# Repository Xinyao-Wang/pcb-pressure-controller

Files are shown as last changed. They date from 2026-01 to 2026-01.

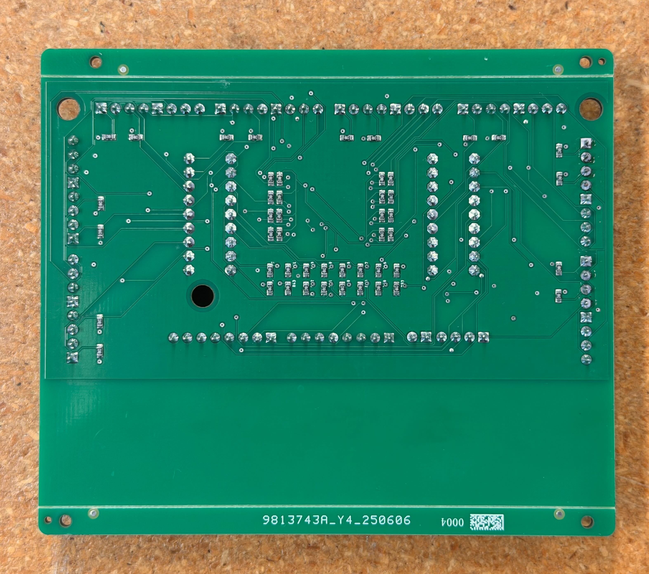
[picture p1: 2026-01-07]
pcb_bottom.jpg

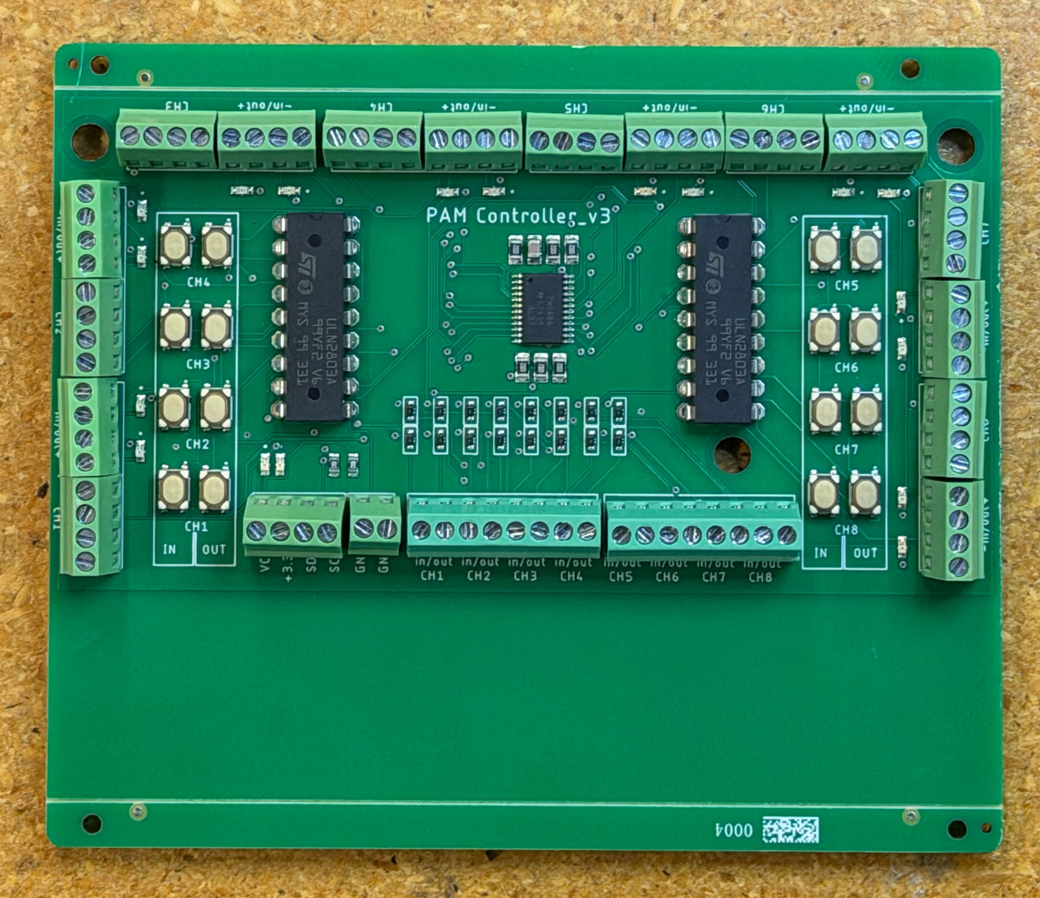
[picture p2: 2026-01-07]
pcb_top.jpg

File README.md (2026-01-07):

# PCB Pressure Controller

This repository contains the PCB design for a pressure control system used to drive and measure pneumatic artificial muscles (PAMs). The board interfaces with multiple pressure sensors and solenoid valves and was validated in hardware experiments.

## System Overview

The PCB performs two main functions:

1. **Pressure sensing** for multiple PAMs using digital pressure sensors over I2C.
2. **Valve actuation** using solenoid valves driven through transistor arrays.

The system was designed to work with a BeagleBone Black as the host controller.

## Pressure Sensing (I2C)

- **Sensor:** Honeywell 150PG2A3  
  - Range: 0–150 psi  
  - Interface: I2C (address 0x28)
- **Challenge:** All sensors share the same fixed I2C address.
- **Solution:** TCA9548A I2C multiplexer
  - Supports up to 8 channels
  - Configured at address `0x70`
  - Allows multiple identical sensors on a single I2C bus

**Electrical details:**
- I2C pull-up resistors: 1.8 kΩ on the main bus
- Sensor-side pull-ups: 1 kΩ
- Multiplexer connected directly to the BeagleBone Black I2C interface

## Valve Control

- **Actuators:** 5 V solenoid valves
- **Driver:** ULN2803A Darlington transistor array
  - Used to sink valve current beyond GPIO capability
  - Protects the controller from inductive loads

### Manual Control and Indicators
- Push-button switches for manual valve actuation
- Per-valve LED indicators showing activation state
- Additional LEDs indicating:
  - Valve power (VCC)
  - Transistor supply power

The valve drive stage is adaptable to valves with different voltage requirements by modifying the supply rail.

## Power

- Valve and transistor power supplied at 5 V
- 5 V rail provided by the BeagleBone Black in the current setup
- Power indicators included for debugging and bring-up

## Repository Contents

- schematic.pdf — Full schematic
- layout.pdf — PCB layout
- pcb_top.jpg — Assembled board (top)
- pcb_bottom.jpg — Assembled board (bottom)
- eagle/ — EAGLE schematic and board files
- CAMOutputs/ — Gerbers
- BOM.csv — Bill of materials

## Design Ownership

I designed the schematic, PCB layout, pressure sensing architecture, and valve driver circuitry, and validated the board in experimental PAM control setups.

## Notes

This PCB was designed for experimental reliability, with clear separation between sensing, actuation, and power domains, and with features added to simplify bring-up and debugging.

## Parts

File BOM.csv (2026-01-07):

Qty | Designator | Footprint | Comment | LCSC part # | Device | Description
1 | J2 | MOLEX-1X2 | Should be a screw terminal 1x2 |  | CONN_02POLAR | Multi connection point. Often used as Generic Header-pin footprint for 0.1 inch spaced/style header connections
17 | J1, J4, J5, J6, J7, J8, J9, J10, J11, J12, J14, J15, J16, J17, J18, J19, J20 | MOLEX-1X4 | Should be screw terminals 1x4 |  | CONN_04POLAR | Multi connection point. Often used as Generic Header-pin footprint for 0.1 inch spaced/style header connections
16 | D19, D20, D21, D22, D23, D24, D25, D26, D27, D28, D29, D30, D31, D32, D33, D34 | SOD-523 | diode | C3040060 | DIODESOD-523 | Diode
1 | U1 | TSSOP24 | TCA9548APWR | C130026 | TCA9548A | TCA9548A I2C Multiplexer
5 | R53, R54, R55, R56, R57, R58 | 0805-NO | 10K | C17414 | RESISTOR0805_NOOUTLINE | Resistors
1 | C1 | 0805-NO | 10uF | C1713 | CAP_CERAMIC0805-NOOUTLINE | Ceramic Capacitors
50 | R3, R4, R5, R6, R7, R8, R9, R10, R11, R12, R13, R14, R15, R16, R17, R18, R19, R20, R21, R22, R23, R24, R25, R26, R27, R28, R29, R30, R31, R32, R33, R34, R35, R36, R37, R38, R39, R40, R41, R42, R43, R44, R45, R46, R47, R48, R49, R50, R51, R52 | RESC1607X60N | 1K | C22548 | RC0603FR-071KL
2 | J3, J13 | TE_282834-8 | Should be screw terminals 1x8 |  | 282834-8
18 | D1, D2, D3, D4, D5, D6, D7, D8, D9, D10, D11, D12, D13, D14, D15, D16, D17, D18 | LEDC1608X35N | LTST-C190KGKT | C125094 | LTST-C190KGKT
16 | S1, S2, S3, S4, S5, S6, S7, S8, S9, S10, S11, S12, S13, S14, S15, S16 | SW_SKRPACE010 | SKRPACE010 | C139797 | SKRPACE010
2 | IC1, IC2 | ULN2803A |  | C73936 | ULN2803A | Eight paths DIP-18 Darlington Transistor Arrays ROHS

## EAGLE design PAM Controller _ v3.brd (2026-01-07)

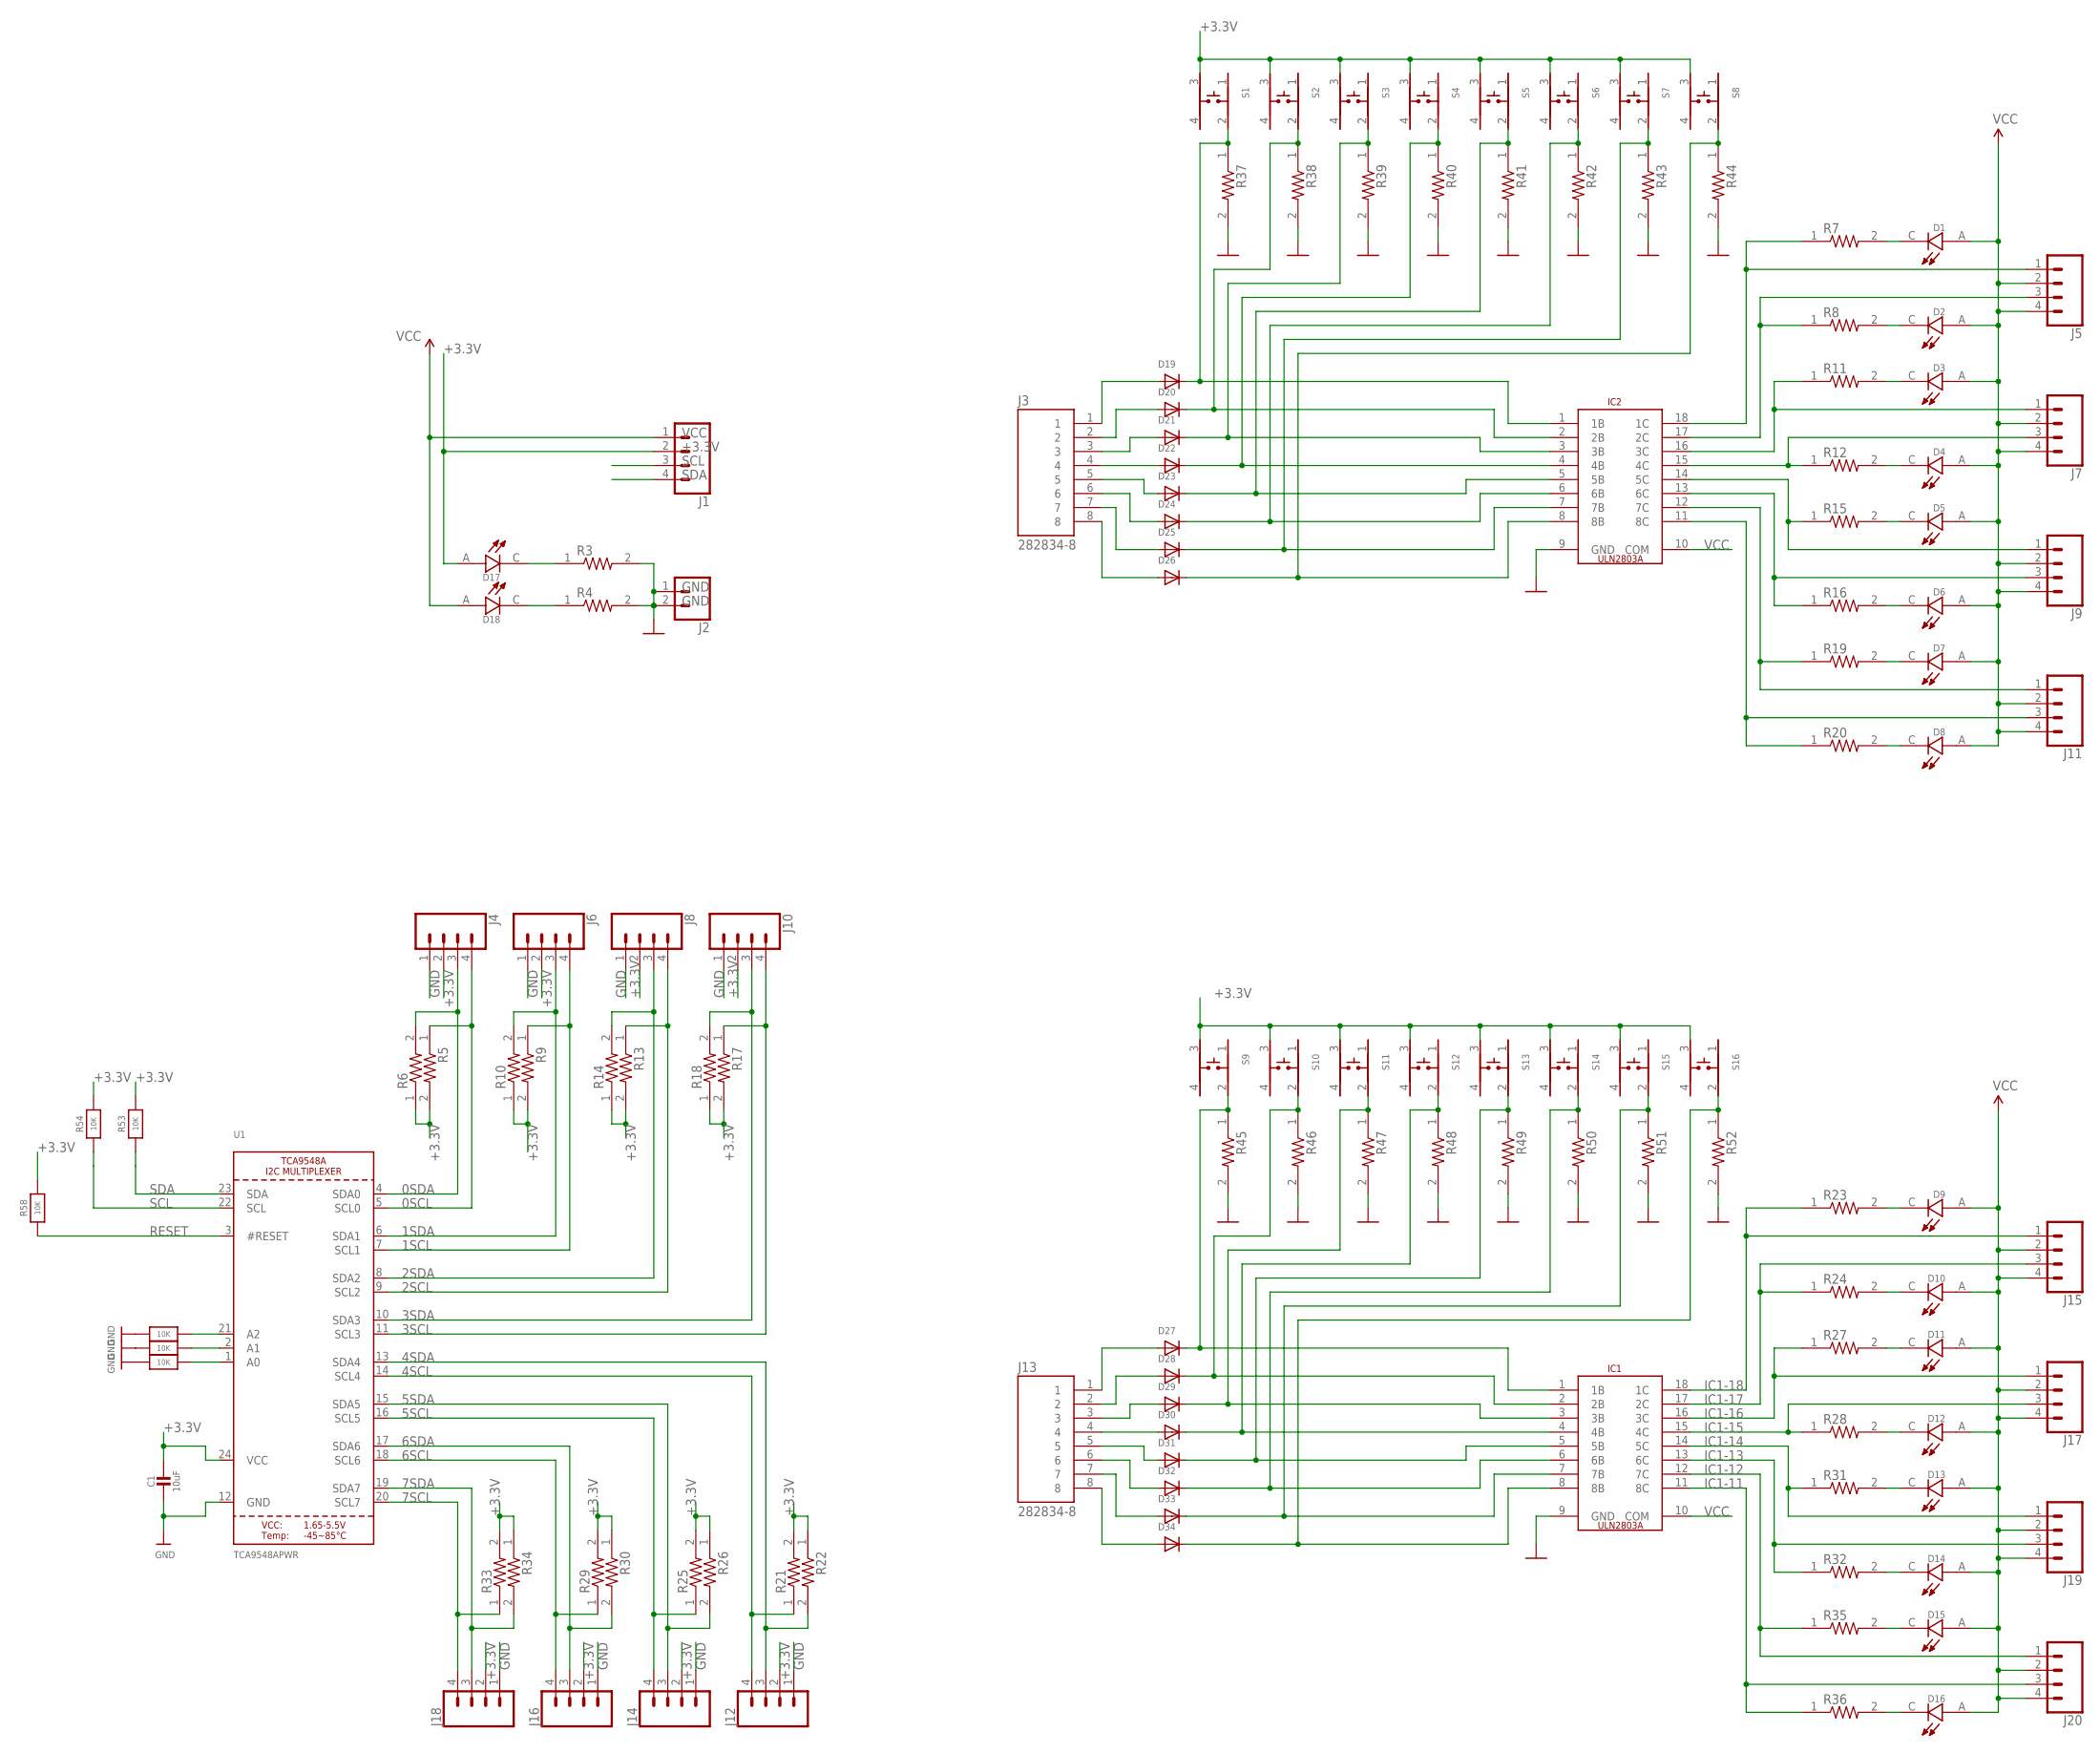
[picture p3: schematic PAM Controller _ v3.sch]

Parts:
C1: 10uF; 0805-NO
D1, D2, D3, D4, D5, D6, D7, D8, D9, D10, D11, D12, D13, D14, D15, D16, D17, D18: LTST-C190KGKT; LEDC1608X35N
D19, D20, D21, D22, D23, D24, D25, D26, D27, D28, D29, D30, D31, D32, D33, D34: DIODESOD-523; SOD-523
IC1, IC2: ULN2803A
J1, J4, J5, J6, J7, J8, J9, J10, J11, J12, J14, J15, J16, J17, J18, J19, J20: CONN_04POLAR; MOLEX-1X4
J2: CONN_02POLAR; MOLEX-1X2
J3, J13: 282834-8; TE_282834-8
R3, R4, R5, R6, R7, R8, R9, R10, R11, R12, R13, R14, R15, R16, R17, R18, R19, R20, R21, R22, R23, R24, R25, R26, R27, R28, R29, R30, R31, R32, R33, R34, R35, R36, R37, R38, R39, R40, R41, R42, R43, R44, R45, R46, R47, R48, R49, R50, R51, R52: 1K; RESC1607X60N
R53, R54, R55, R56, R57, R58: 10K; 0805-NO
S1, S2, S3, S4, S5, S6, S7, S8, S9, S10, S11, S12, S13, S14, S15, S16: SKRPACE010; SW_SKRPACE010
U1: TCA9548APWR; TSSOP24

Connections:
0SCL: J4.4, R5.1, U1.5 (SCL0)
0SDA: J4.3, R6.2, U1.4 (SDA0)
1SCL: J6.4, R9.1, U1.7 (SCL1)
1SDA: J6.3, R10.2, U1.6 (SDA1)
2SCL: J8.4, R13.1, U1.9 (SCL2)
2SDA: J8.3, R14.2, U1.8 (SDA2)
3SCL: J10.4, R17.1, U1.11 (SCL3)
3SDA: J10.3, R18.2, U1.10 (SDA3)
4SCL: J12.4, R21.1, U1.14 (SCL4)
4SDA: J12.3, R22.2, U1.13 (SDA4)
5SCL: J14.4, R25.1, U1.16 (SCL5)
5SDA: J14.3, R26.2, U1.15 (SDA5)
6SCL: J16.4, R29.1, U1.18 (SCL6)
6SDA: J16.3, R30.2, U1.17 (SDA6)
7SCL: J18.4, R33.1, U1.20 (SCL7)
7SDA: J18.3, R34.2, U1.19 (SDA7)
+3.3V: C1.1, D17.A, J1.2, J4.2, J6.2, J8.2, J10.2, J12.2, J14.2, J16.2, J18.2, R5.2, R6.1, R9.2, R10.1, R13.2, R14.1, R17.2, R18.1, R21.2, R22.1, R25.2, R26.1, R29.2, R30.1, R33.2, R34.1, R53.2, R54.2, R58.2, S1.3, S2.3, S3.3, S4.3, S5.3, S6.3, S7.3, S8.3, S9.3, S10.3, S11.3, S12.3, S13.3, S14.3, S15.3, S16.3, U1.24 (VCC)
GND: C1.2, IC1.9 (GND), IC2.9 (GND), J2.1, J2.2, J4.1, J6.1, J8.1, J10.1, J12.1, J14.1, J16.1, J18.1, R3.2, R4.2, R37.2, R38.2, R39.2, R40.2, R41.2, R42.2, R43.2, R44.2, R45.2, R46.2, R47.2, R48.2, R49.2, R50.2, R51.2, R52.2, R55.2, R56.2, R57.2, U1.12 (GND)
IC1-11: IC1.11 (8C), J20.3, R36.1
IC1-12: IC1.12 (7C), J20.1, R35.1
IC1-13: IC1.13 (6C), J19.3, R32.1
IC1-14: IC1.14 (5C), J19.1, R31.1
IC1-15: IC1.15 (4C), J17.3, R28.1
IC1-16: IC1.16 (3C), J17.1, R27.1
IC1-17: IC1.17 (2C), J15.3, R24.1
IC1-18: IC1.18 (1C), J15.1, R23.1
IC2-11: IC2.11 (8C), J11.3, R20.1
IC2-12: IC2.12 (7C), J11.1, R19.1
IC2-13: IC2.13 (6C), J9.3, R16.1
IC2-14: IC2.14 (5C), J9.1, R15.1
IC2-15: IC2.15 (4C), J7.3, R12.1
IC2-16: IC2.16 (3C), J7.1, R11.1
IC2-17: IC2.17 (2C), J5.3, R8.1
IC2-18: IC2.18 (1C), J5.1, R7.1
unnamed: D19.K (C), IC2.1 (1B), R37.1, S1.2
unnamed: D19.A, J3.1
unnamed: D20.A, J3.2
unnamed: D21.A, J3.3
unnamed: D22.A, J3.4
unnamed: D23.A, J3.5
unnamed: D24.A, J3.6
unnamed: D25.A, J3.7
unnamed: D27.A, J13.1
unnamed: D27.K (C), IC1.1 (1B), R45.1, S9.2
unnamed: R56.1, U1.2 (A1)
unnamed: R57.1, U1.1 (A0)
unnamed: D28.K (C), IC1.2 (2B), R46.1, S10.2
unnamed: R55.1, U1.21 (A2)
unnamed: D30.A, J13.4
unnamed: D28.A, J13.2
unnamed: D29.A, J13.3
unnamed: D34.A, J13.8
unnamed: D33.A, J13.7
unnamed: D14.C, R32.2
unnamed: D15.C, R35.2
unnamed: D26.A, J3.8
unnamed: D32.A, J13.6
unnamed: D20.K (C), IC2.2 (2B), R38.1, S2.2
unnamed: D21.K (C), IC2.3 (3B), R39.1, S3.2
unnamed: D22.K (C), IC2.4 (4B), R40.1, S4.2
unnamed: D23.K (C), IC2.5 (5B), R41.1, S5.2
unnamed: D24.K (C), IC2.6 (6B), R42.1, S6.2
unnamed: D25.K (C), IC2.7 (7B), R43.1, S7.2
unnamed: D26.K (C), IC2.8 (8B), R44.1, S8.2
unnamed: D29.K (C), IC1.3 (3B), R47.1, S11.2
unnamed: D31.A, J13.5
unnamed: D30.K (C), IC1.4 (4B), R48.1, S12.2
unnamed: D31.K (C), IC1.5 (5B), R49.1, S13.2
unnamed: D32.K (C), IC1.6 (6B), R50.1, S14.2
unnamed: D33.K (C), IC1.7 (7B), R51.1, S15.2
unnamed: D34.K (C), IC1.8 (8B), R52.1, S16.2
unnamed: D16.C, R36.2
unnamed: D12.C, R28.2
unnamed: D13.C, R31.2
unnamed: D11.C, R27.2
unnamed: D10.C, R24.2
unnamed: D9.C, R23.2
unnamed: D8.C, R20.2
unnamed: D7.C, R19.2
unnamed: D6.C, R16.2
unnamed: D1.C, R7.2
unnamed: D17.C, R3.1
unnamed: D18.C, R4.1
unnamed: D5.C, R15.2
unnamed: D4.C, R12.2
unnamed: D3.C, R11.2
unnamed: D2.C, R8.2
RESET: R58.1, U1.3 (#RESET)
SCL: J1.4, R54.1, U1.22 (SCL)
SDA: J1.3, R53.1, U1.23 (SDA)
VCC: D1.A, D2.A, D3.A, D4.A, D5.A, D6.A, D7.A, D8.A, D9.A, D10.A, D11.A, D12.A, D13.A, D14.A, D15.A, D16.A, D18.A, IC1.10 (COM), IC2.10 (COM), J1.1, J5.2, J5.4, J7.2, J7.4, J9.2, J9.4, J11.2, J11.4, J15.2, J15.4, J17.2, J17.4, J19.2, J19.4, J20.2, J20.4

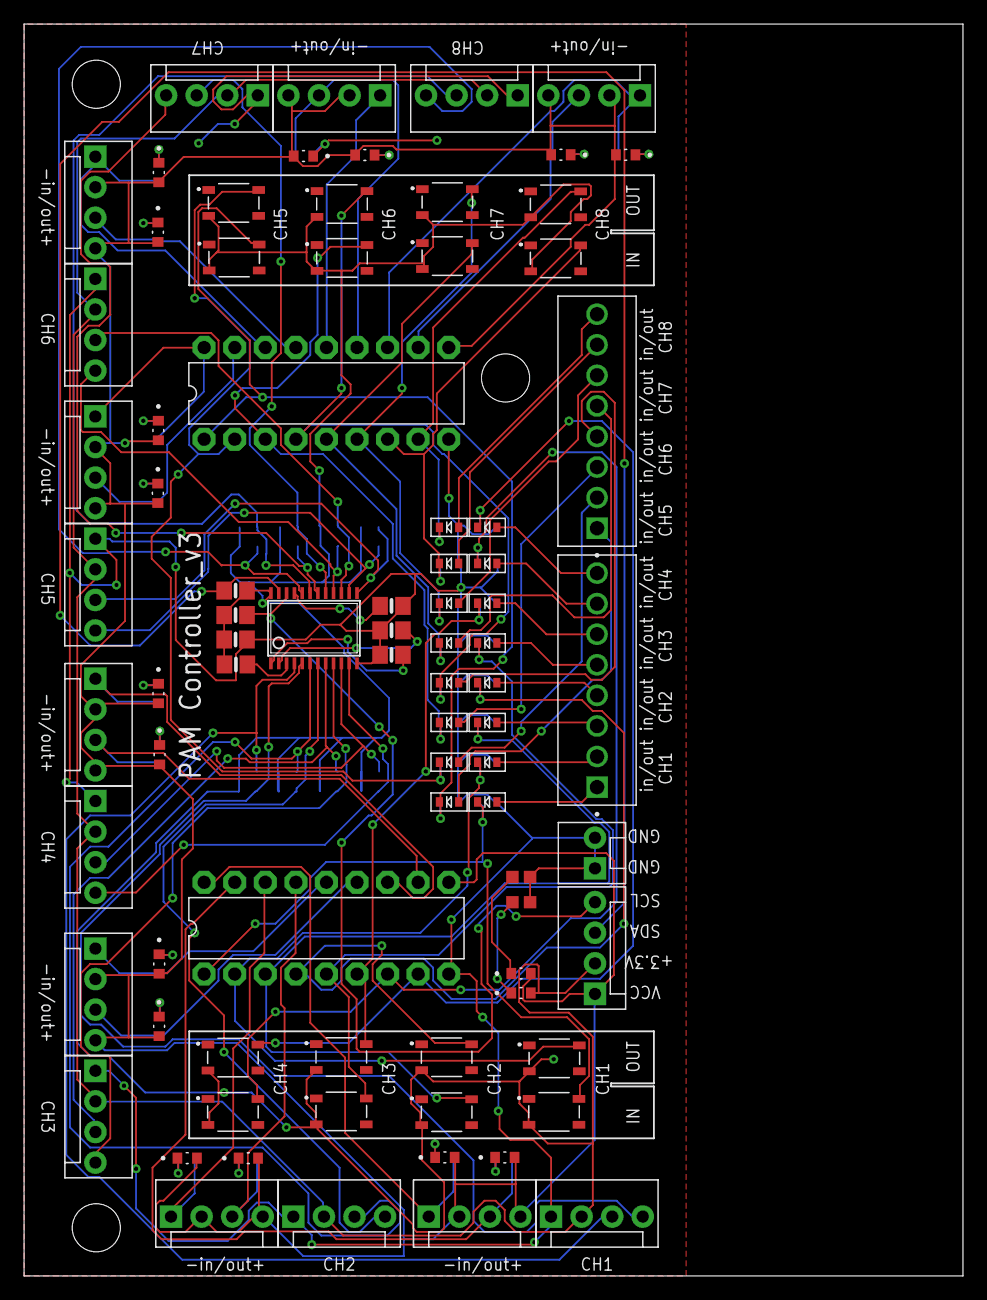
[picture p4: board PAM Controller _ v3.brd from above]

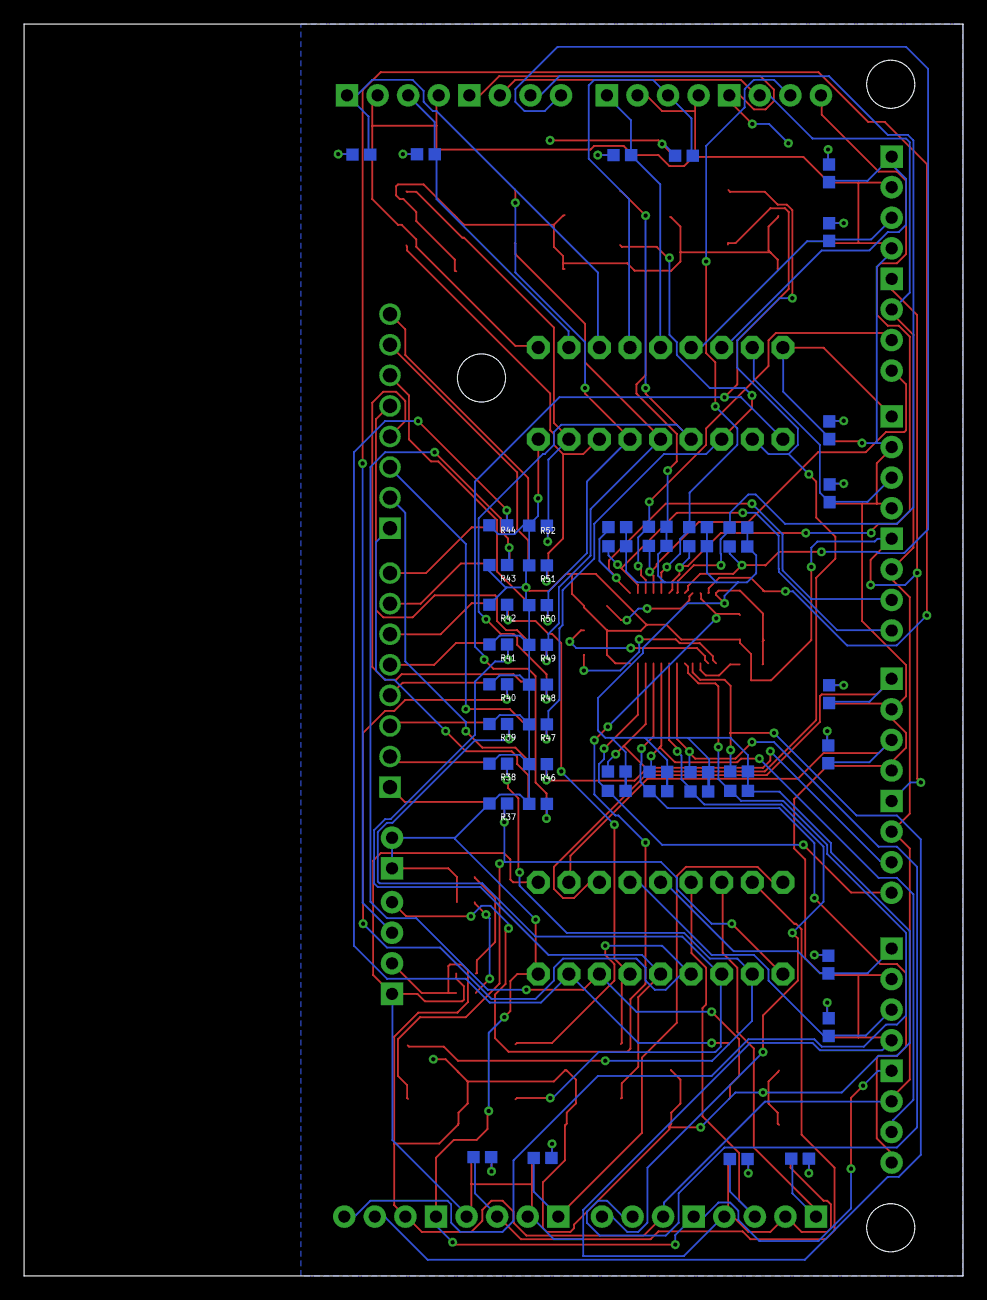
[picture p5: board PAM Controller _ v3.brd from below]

Board: 2 copper layers, 78.0 x 104.0 mm, 130 parts (48 on the bottom side), 91 nets.

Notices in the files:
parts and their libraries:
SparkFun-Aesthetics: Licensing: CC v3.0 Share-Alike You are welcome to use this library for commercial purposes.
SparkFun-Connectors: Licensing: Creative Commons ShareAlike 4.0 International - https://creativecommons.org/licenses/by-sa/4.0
